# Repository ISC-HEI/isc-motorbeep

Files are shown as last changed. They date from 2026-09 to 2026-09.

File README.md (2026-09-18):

<picture>
  <source media="(prefers-color-scheme: dark)"
          srcset="https://raw.githubusercontent.com/ISC-HEI/isc-logos/main/white/ISC%20Logo%20inline%20white%20v3%20-%20large.webp">
  ISC Logo
</picture>

# ISC MotorBeep — ESP32 dual-stepper + audio board

A complete [KiCad 9](https://www.kicad.org/) schematic for an ESP32 board driving two bipolar
stepper motors and a small speaker, powered from 3× AA cells. It is an improved derivative of the
ESP32 DevKit DOIT v1: the AMS1117 LDO, the thin bulk capacitance, the micro-USB connector and the
absent battery sensing are all addressed.

## The brief

Take the [ESP32 DevKit DOIT v1](https://embedded-systems-design.github.io/overview-of-the-esp32-devkit-doit-v1/)
as the reference design and produce an improved version of it that drives **two stepper motors** and
a **small speaker**, running off **AA cells** — originally two, changed to three during the work.
Deliver the complete schematic in KiCad (installing it as needed), authored through the
[KiCAD-MCP-Server](https://github.com/mixelpixx/KiCAD-MCP-Server).

## What was built

1. KiCad 9 installed, the MCP server built, and patched — it emits the KiCad 10 file format, which 9 refuses to load.
2. Architecture chosen from the battery up: 3× AA (2.8–4.8 V) sits inside the STSPIN220 and MAX98357A supply windows, so motors and audio need no converter; only the ESP32 does, and it must be a buck-boost.
3. Parts picked against what KiCad actually ships — `DRV8834` and `TPS63020` have no stock symbols, so `STSPIN220` and `TPS63001` replaced them.
4. Four hierarchical sheets authored headlessly: power, MCU, motors, audio. **Root ERC: 0 errors.**
5. Verified three ways — ERC, a rendered image of every sheet reviewed by eye, and `check_nets.py`, which asserts 29 design-intent connections against the exported netlist.
6. Footprints assigned and checked to exist, netlist and PDF exported, BOM priced against the real JLCPCB catalog (**$14.49**, part links in [`doc/BOM.md`](./doc/BOM.md)).
7. A 4-layer PCB created and fully placed — antenna overhanging the edge, switching nodes 4.3 mm — then rendered in 3D. **Routing was not done.**

## Schematic

Four hierarchical sheets plus a root. Click any image for full resolution, or read
[the complete PDF](./doc/isc-motorbeep-schematic.pdf).

### Root — sheet hierarchy

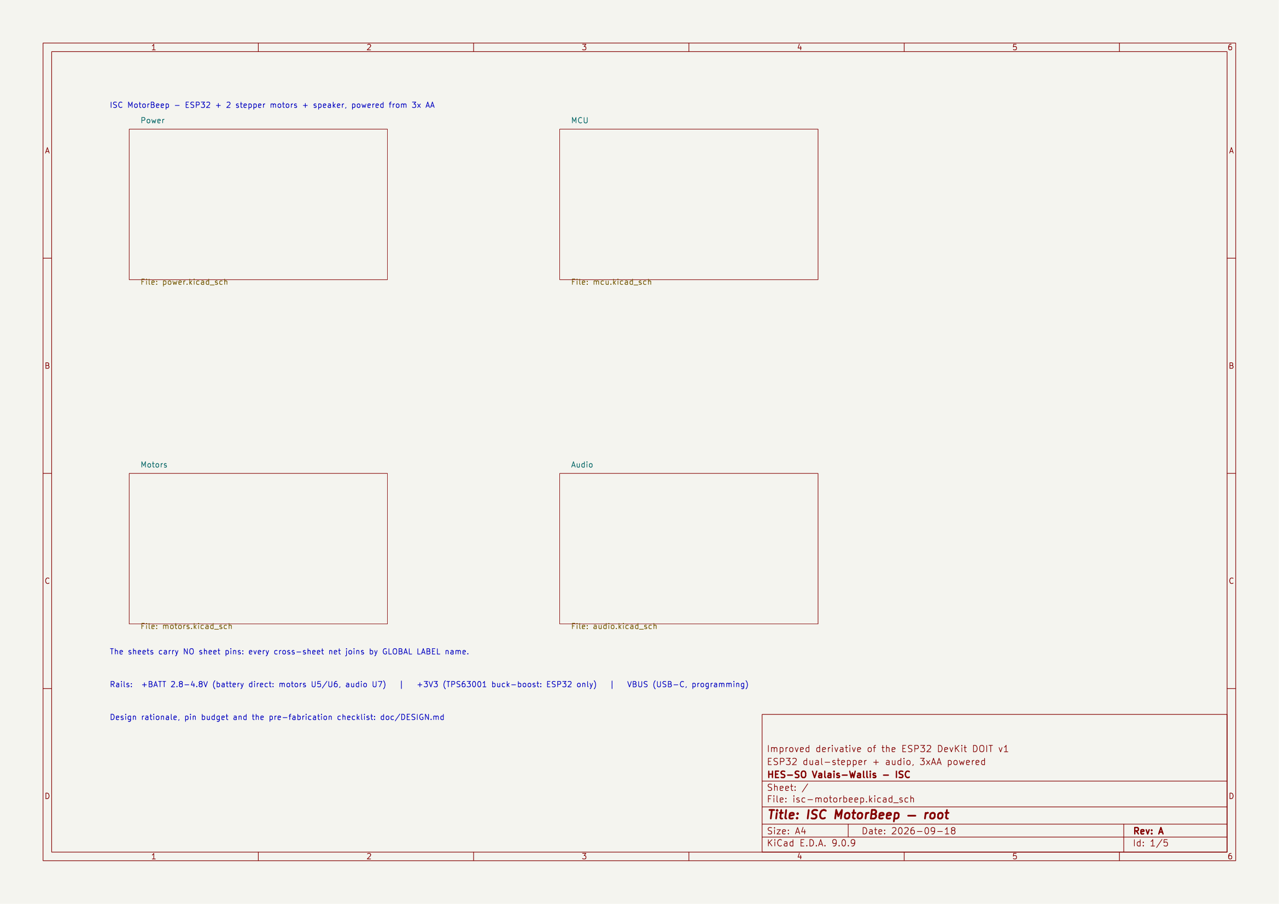
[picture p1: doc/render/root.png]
Root sheet


### Power — 3× AA, Schottky OR, TPS63001 buck-boost, USB-C

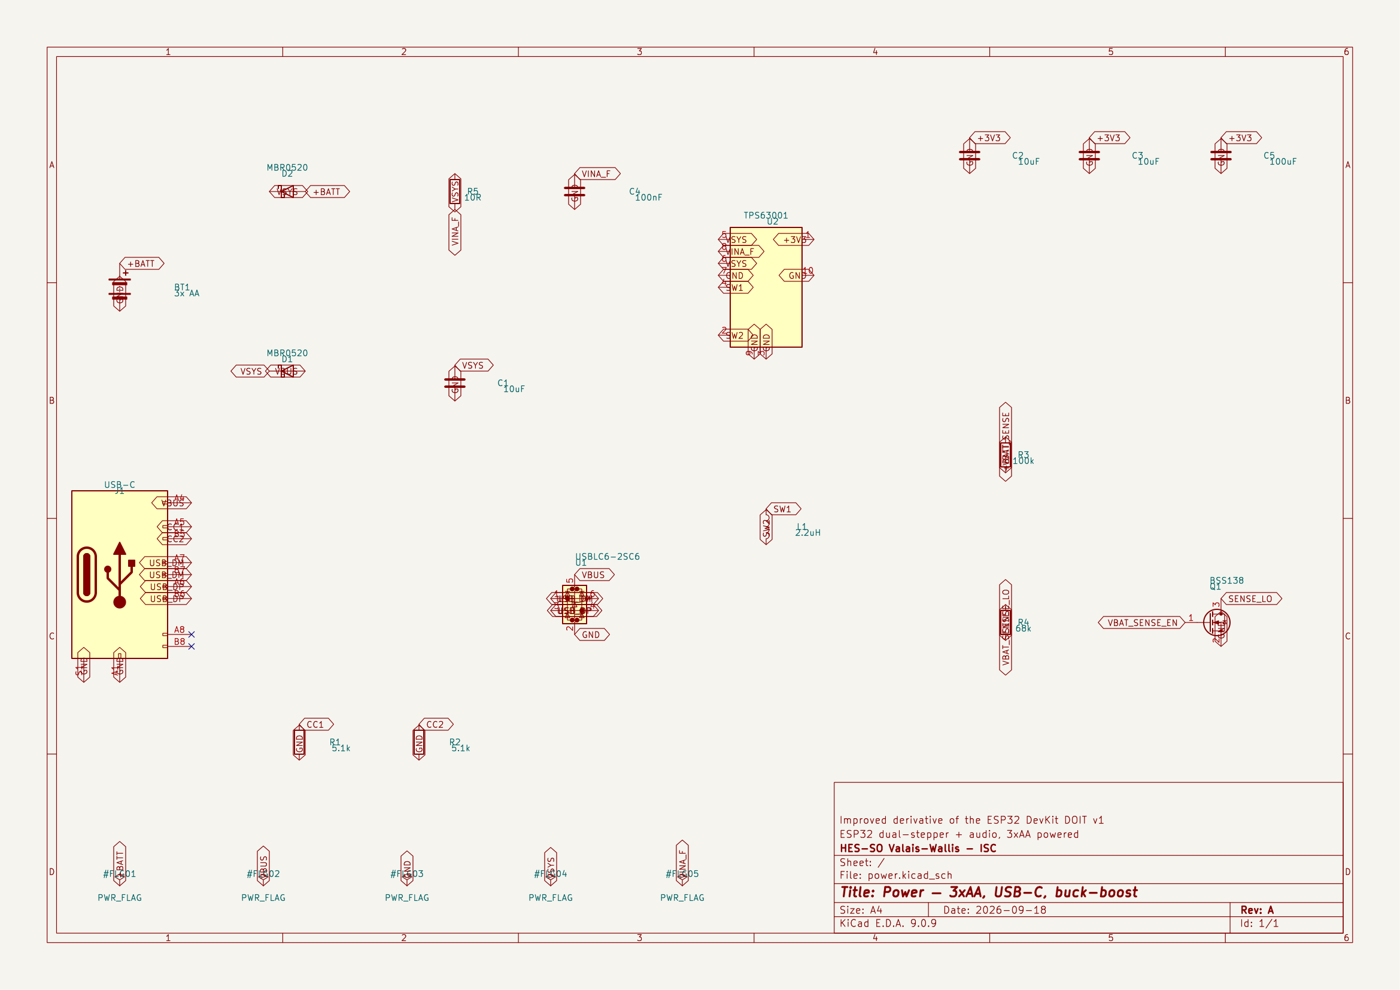
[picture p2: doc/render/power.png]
Power sheet


### MCU — ESP32-WROOM-32E, CP2102N bridge, auto-reset

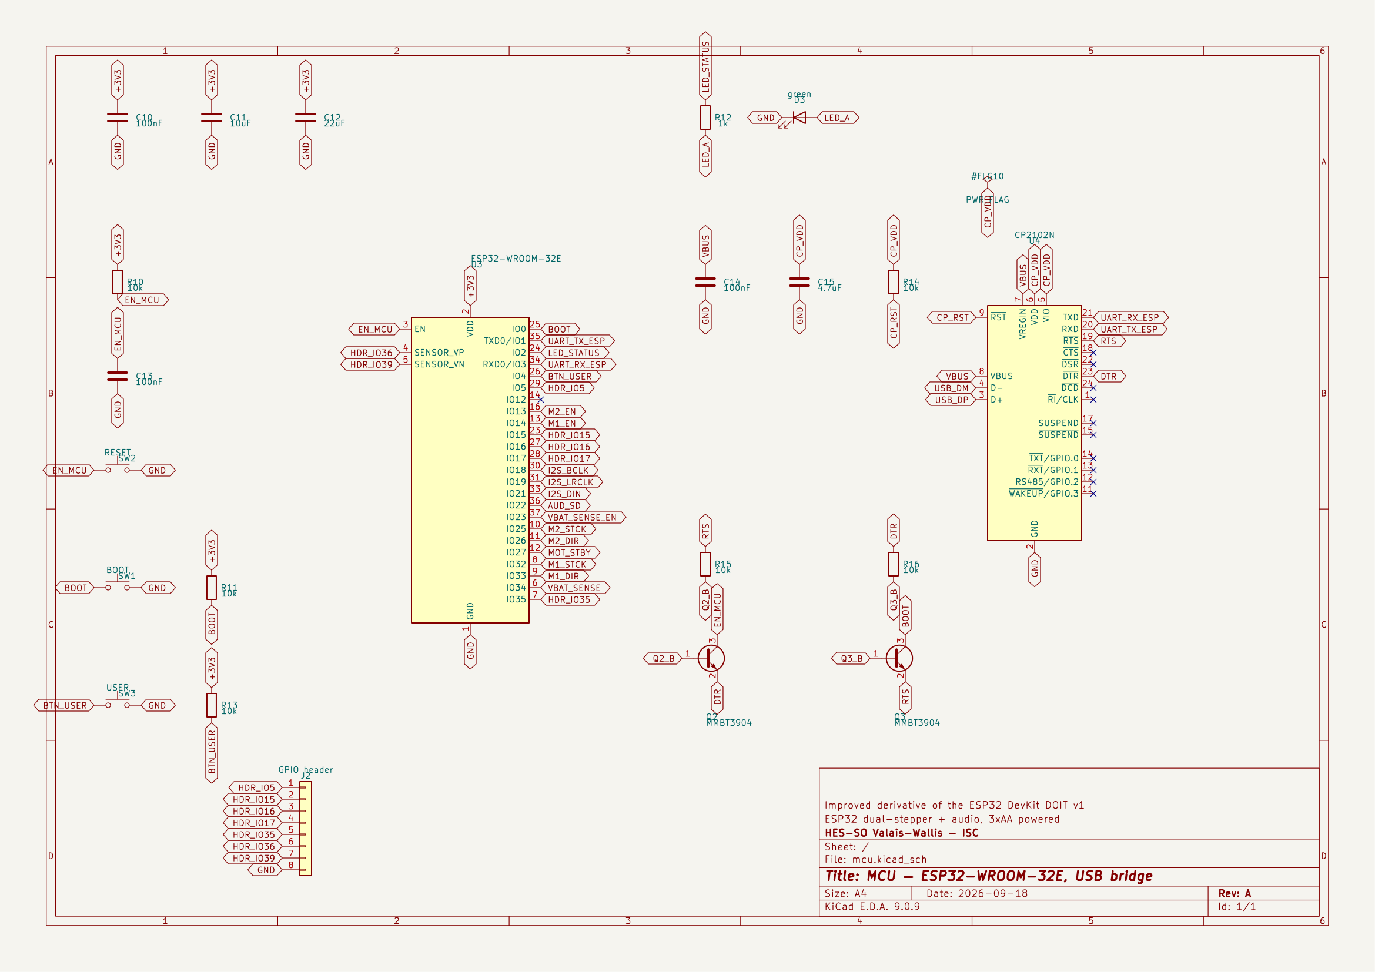
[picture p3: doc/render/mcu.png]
MCU sheet


### Motors — 2× STSPIN220 stepper drivers

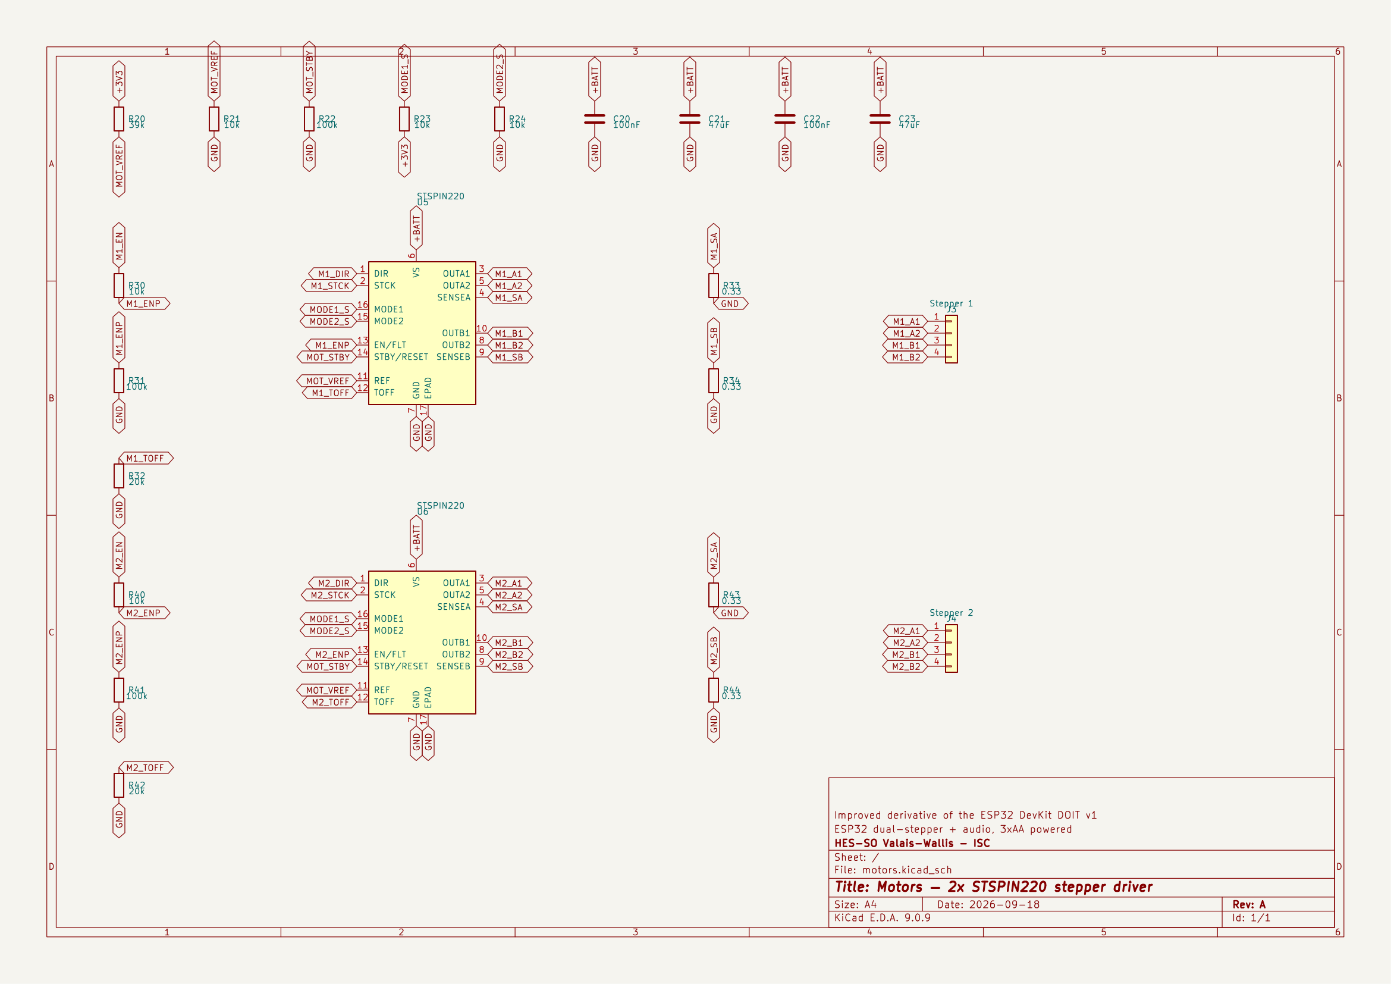
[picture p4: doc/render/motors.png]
Motors sheet


### Audio — MAX98357A Class-D

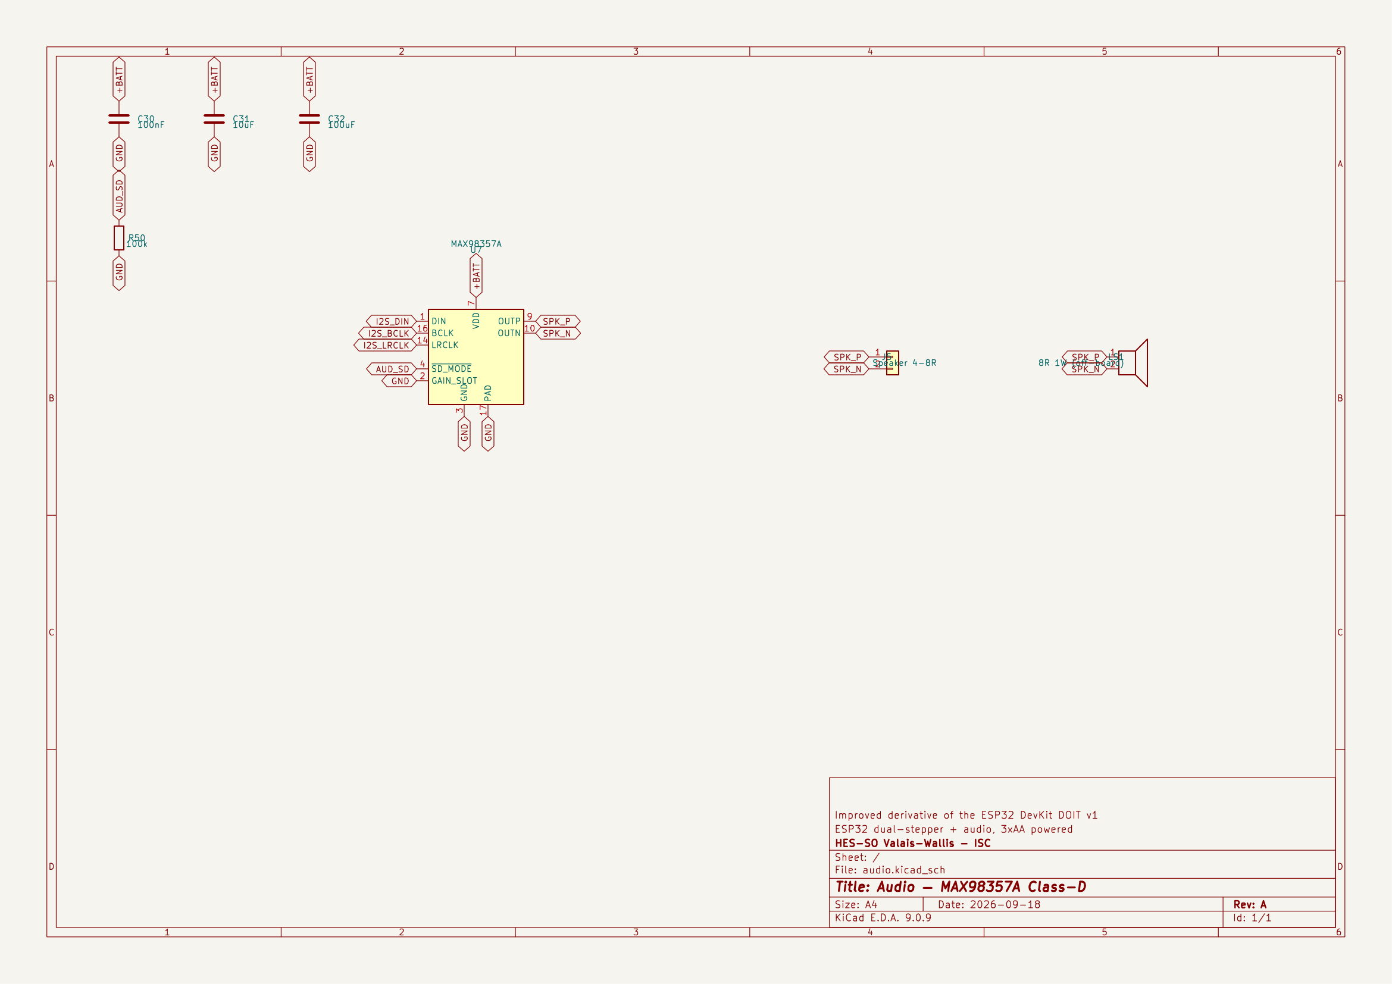
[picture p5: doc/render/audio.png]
Audio sheet


## PCB

Placed, not routed. 70 x 50 mm, 4 layers, 69 footprints, verified by
[`tools/place_board.py`](./tools/place_board.py): no overlaps, nothing off-board, and nothing
inside the ESP32 antenna keepout. The module's antenna deliberately overhangs the top edge, and
L1 sits directly left of the TPS63001 so both switching nodes come out as 4.3 mm straight runs.

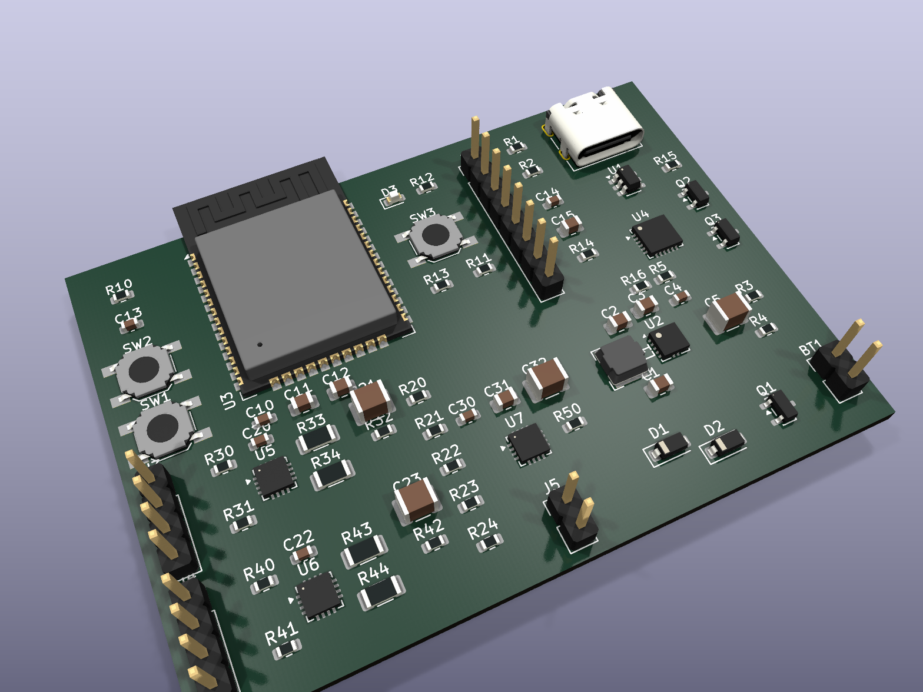
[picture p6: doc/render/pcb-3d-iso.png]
PCB 3D view


Routing is not done, so there are no tracks and no copper pours yet.

## Architecture

Three AA cells deliver 2.8–4.8 V, and that range sits inside the supply window of both power loads —
the STSPIN220 works from 1.8 V and the MAX98357A from 2.5 V — so the motors and the speaker run
straight off the pack with no converter at all. Only the ESP32 needs one, and it has to be a
buck-boost: the pack starts above 3.3 V and ends below it, so an LDO would drop out and a plain
boost could not regulate down. USB and battery are OR'd through two Schottky diodes into that
converter only, which is what stops USB from back-feeding and charging the alkaline cells.

```mermaid
flowchart LR
    B["3x AA / 2.8-4.8 V"] --> D2["D2 Schottky"]
    U["USB-C 5 V"] --> D1["D1 Schottky"]
    D1 --> V["VSYS"]
    D2 --> V
    V --> R["U2 TPS63001 buck-boost"]
    R --> L3["+3V3 - ESP32 only"]
    B --> M["U5/U6 STSPIN220 - 2 steppers"]
    B --> A["U7 MAX98357A - speaker"]
```

Every line the ESP32 gates has a resistor defining its state at reset, so the motors cannot twitch
and the speaker cannot pop at power-up; `GPIO12` is left unconnected because it straps the flash
voltage. The reasoning, the full pin budget and the pre-fabrication checklist are in
**[`doc/DESIGN.md`](./doc/DESIGN.md)**.

## Bill of materials

70 components in 36 lines, about **$14.49** in parts at 1-off LCSC prices (catalog snapshot of
14 September 2026). Full priced BOM with a part link per line: **[`doc/BOM.md`](./doc/BOM.md)**.

> [!WARNING]
> **The STSPIN220 was down to 27 units at JLCPCB in that snapshot** — check it live before
> committing to a build. `doc/BOM.md` names the substitute and what swapping costs you.

Almost every part is a JLCPCB *Extended* part with a $3 setup fee each, so for a one-off, hand
assembly is cheaper than paying the setup fees.

## Open it

```bash
kicad hardware/isc-motorbeep/isc-motorbeep.kicad_pro
```

Generated headlessly through the KiCAD-MCP-Server — reproduction steps, the KiCad 9 file-format
patch it needs, and the helper scripts are in [`doc/TOOLING.md`](./doc/TOOLING.md).

## Before fabricating

The schematic is complete and ERC-clean, but two questions could not be settled without
manufacturer datasheets. Both are detailed, with the rest of the checklist, in
[`doc/DESIGN.md` §8.5–8.6](./doc/DESIGN.md):

- **Are the STSPIN220 and MAX98357A logic inputs rated independently of their supply?** The ESP32
  drives 3.3 V into them while `+BATT` may be at 2.8 V. If either is VS-referenced, the design
  breaks at low battery. This is the one that matters.
- **The QFN-16 exposed-pad dimension** for U5/U6/U7 — stock footprint variants run 1.45 to 1.85 mm,
  and it is the thermal path the current-chopping depends on.

---

## License

Copyright © 2026 P.-A. Mudry / ISC — HES-SO Valais. Released under
[CC-BY-NC-ND 4.0](https://creativecommons.org/licenses/by-nc-nd/4.0/).

---

*Made with ♥ by mui, 2026*

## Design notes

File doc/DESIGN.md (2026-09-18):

# ISC MotorBeep — ESP32 dual-stepper + audio board, 3xAA powered

Improved derivative of the ESP32 DevKit DOIT v1.
Target: 2 stepper motors + 1 small speaker, powered from 3x AA cells.

## 1. The supply: 3x AA

| Chemistry | Fresh | Nominal | Practical cutoff | Usable energy |
|---|---|---|---|---|
| Alkaline 3xAA  | 4.8 V | 4.5 V | ~2.8 V | ~11 Wh at low current |
| NiMH 3xAA | 4.2 V | 3.6 V | 3.0 V | ~7 Wh, good pulse behaviour |

Going from 2 to 3 cells changes the architecture, it does not just add margin:

- **The motor and audio rails no longer need a converter.** The pack stays
  inside the STSPIN220 (1.8-10 V) and MAX98357A (2.5-5.5 V) supply ranges for
  the whole discharge, so both run **straight off VBAT**. The 5 V boost that
  2xAA forced is deleted: fewer parts, less EMI, and no conversion loss on the
  dominant load.
- **The 3.3 V logic rail still needs a buck-boost.** The pack starts at 4.8 V
  (above 3.3) and ends at 2.8 V (below it), so it crosses the output voltage.
  An LDO would drop out; a plain boost cannot regulate down. This stays
  non-negotiable.
- ~50% more energy than 2xAA, and the boost is gone, so runtime improves by
  appreciably more than 50%.

**Still recommended: NiMH (Eneloop) over alkaline.** Alkaline internal
resistance rises steeply as it discharges, and stepper coil current is pulsed;
the pack voltage will sag under each step. NiMH holds up far better.

## 2. Power architecture

    3xAA --> VBAT (2.8-4.8 V)
      |
      +--> U5, U6  STSPIN220   VS   direct   (1.8-10 V range)   motors
      +--> U7      MAX98357A   VDD  direct   (2.5-5.5 V range)  audio
      +--> U2      TPS63001 buck-boost -----> +3V3              ESP32 + logic

One converter in the whole design. `TPS63001` is the fixed-3.3 V member of the
TPS63000 family (Vin 1.8-5.5 V, 1.7 A switch); on the fixed-output parts **FB is
tied to GND**. Powering the ESP32 through a buck-boost also means it rides
through the VBAT sag caused by motor current pulses instead of browning out.

There is **no load switch** on the motor/audio domain: the STSPIN220 `STBY` and
the MAX98357A `SD_MODE` already put those parts in sub-microamp standby, so a
series FET would add loss and parts for nothing.

### 2.1 USB power path — and the back-feed trap it avoids

USB is for programming, but the board must also be usable with the pack in
place, so the two sources have to be OR'd **without letting USB charge the
batteries**. Alkaline cells being charged is a leak-and-rupture hazard.

The obvious circuit is wrong: a P-MOSFET reverse-polarity "ideal diode" with its
gate at GND is only a diode *until it turns on* — after that it conducts in both
directions. With VBUS = 5 V sitting above VBAT = 4.8 V it would push current
straight back into the pack. So:

    VBUS ---|>|--- D1 Schottky ---+
                                  +--- VIN of U2 (TPS63001) only
    VBAT ---|>|--- D2 Schottky ---+

    VBAT ------------------------------> motors + audio  (battery only, never USB)

- Diodes, not a FET, on the OR: they cannot conduct backwards, so USB can never
  reach the cells.
- The OR feeds **only the 3.3 V converter**. Motors and audio stay on the
  battery, which also stops a 500 mA USB port being asked to drive two steppers.
- Schottky drop ~0.3 V: at a flat pack, 2.8 - 0.3 = 2.5 V, still above the
  TPS63001 1.8 V minimum.
- The reverse-polarity FET is therefore only needed in the battery leg; with
  the Schottky there it becomes optional (see 8.5).

## 3. Stepper drivers — STSPIN220

**STSPIN220 x2** (U5, U6), QFN16 + exposed pad. Chosen because its supply range
starts at **1.8 V**: the usual A4988 / DRV8825 need 8 V and simply cannot run
from a battery pack this size. STEP/DIR ("STCK"/"DIR") interface, microstepping
to 1/256, integrated current control.

Motors are small **bipolar** steppers. Bipolar with current chopping is far more
efficient per unit of torque than the classic 28BYJ-48 unipolar + ULN2003, which
burns power in a Darlington array and has no current regulation at all.

Per-driver pins that need deliberate treatment:

| Pin | # | Treatment |
|---|---|---|
| `STCK`, `DIR` | 2, 1 | from ESP32 |
| `MODE1`, `MODE2` | 16, 15 | resistor straps -> microstep mode |
| `STBY/RESET` | 14 | **pull-down**; ESP32 raises to leave standby |
| `EN/FLT` | 13 | bidirectional: 10k series from GPIO + pull-down, so the open-drain fault can pull it low without fighting the GPIO |
| `REF` | 11 | divider from +3V3 sets the current limit |
| `TOFF` | 12 | resistor to GND sets the chopper off-time |
| `SENSEA`, `SENSEB` | 4, 9 | sense resistors to GND |
| `EPAD` | 17 | to GND — it is the thermal path |

**Microstep latching:** on the STSPIN220 the mode is latched when the device
leaves standby, and `MODE3`/`MODE4` are *multiplexed onto the `STCK`/`DIR`
pins*. Firmware must therefore set STCK/DIR to the wanted mode bits **before**
raising `STBY`, not after. This is the single easiest thing to get wrong.

## 4. Audio

**MAX98357A** (U7): I2S digital input -> Class-D output, 2.5-5.5 V supply,
~92% efficient, no separate DAC needed. Replaces the ESP32's own 8-bit DAC +
analog amp: better SNR, and Class-D matters when the energy budget is 5 Wh.
Runs directly from **VBAT**, `SD_MODE` gated by the ESP32 to mute/shutdown.

## 5. What is actually improved vs. the DOIT DevKit v1

| DOIT v1 weakness | Fix here |
|---|---|
| AMS1117 LDO: ~1.1 V dropout, no low-power mode, burns Vin-Vout as heat | TPS63001 buck-boost; motors/audio need no converter at all |
| Thin bulk capacitance near module -> brownout on WiFi TX bursts | 22 uF bulk + 10 uF + 100 nF at the module, plus a 100 uF reservoir on +3V3 |
| Micro-USB | USB-C receptacle, CC1/CC2 5.1k pulldowns |
| CP2102 (old), no ESD protection on USB | CP2102N + USBLC6-2SC6 ESD array |
| No reverse-polarity protection | Schottky D2 in the battery leg (also the OR-ing diode) |
| No battery sensing | divider on an **ADC1** pin, gated by a MOSFET so it draws nothing when idle |
| ADC2 pins unusable while WiFi is on (silent trap) | all analog routed to ADC1 only |
| Strapping pins exposed with no guidance | GPIO0/2/15 kept free of boot-breaking loads; **GPIO12 left NC** (anything on it risks a bad flash-voltage strap) |
| EN/BOOT buttons with marginal RC | proper RC + the two-transistor DTR/RTS auto-reset |

## 6. Sheet plan (hierarchical)

1. `power.kicad_sch`  — battery, Schottky OR, TPS63001 buck-boost, USB-C + ESD, battery sensing
2. `mcu.kicad_sch`    — ESP32-WROOM-32E, decoupling, CP2102N, auto-reset, buttons, LED
3. `motors.kicad_sch` — 2x STSPIN220 + shared bias/straps + connectors
4. `audio.kicad_sch`  — MAX98357A + speaker connector

## 7. Pin budget (ESP32-WROOM-32E)

| Function | GPIO | Note |
|---|---|---|
| M1 `STCK` / `DIR` | 32 / 33 | also carry MODE3/MODE4 at standby exit |
| M2 `STCK` / `DIR` | 25 / 26 | idem |
| Motors `STBY` (shared) | 27 | pull-down: both drivers asleep at reset |
| M1 `EN/FLT` | 14 | 10k series, bidirectional fault line |
| M2 `EN/FLT` | 13 | separate, so a fault is attributable to one motor |
| I2S `BCLK` / `LRCLK` / `DIN` | 18 / 19 / 21 | MAX98357A |
| Audio `SD_MODE` | 22 | mute / channel select |
| VBAT sense | 34 | **ADC1**_CH6, input-only pin |
| VBAT sense gate | 23 | MOSFET, divider draws nothing when idle |
| Status LED | 2 | strapping pin; LED to GND is the safe use |
| User button | 4 | |
| BOOT button | 0 | with the DTR/RTS auto-reset |
| — | **12** | **left NC** — MTDI straps the flash voltage |

Free and brought to a header: GPIO5, 15, 35, 36, 39.

## 8. Detail decisions (review pass)

Things that are easy to get wrong and are fixed deliberately here.

### 8.1 Default-safe straps — the important one
At ESP32 reset every GPIO is high-Z. Anything the ESP32 gates must therefore
have a resistor defining the safe state, or the motors twitch and the speaker
pops at power-up:

| Net | Pull | Why |
|---|---|---|
| `MOT_STBY` (GPIO27 -> both STSPIN220 `STBY`) | 100k **pull-down** | drivers stay in standby, coils unpowered |
| `M1_EN`, `M2_EN` (GPIO14/13 -> `EN/FLT`) | 100k **pull-down** + 10k series | outputs disabled; series R lets the open-drain fault win without fighting the GPIO |
| `AUD_SD` (GPIO22 -> `SD_MODE`) | see 8.3 | amp muted until driven |

**Caveat on GPIO14 (`M1_EN`).** GPIO14 is MTMS and has an *internal pull-up*
active during boot. Through the 10k series resistor against the 100k pull-down
it settles around 2 V, i.e. a logic HIGH, so `M1_EN` is briefly asserted while
the ESP32 boots. This is harmless **only because `STBY` (GPIO27) is the master
gate and has no boot pull** — the driver stays in standby regardless, so no
current reaches the coils. If that ordering ever changes, move the EN lines to
GPIO16/17, which have no boot pulls.

### 8.2 STSPIN220 — current limit and the two easy mistakes
Phase current is set by the `REF` voltage together with the `SENSEA`/`SENSEB`
resistors; `TOFF` sets the chopper off-time. Planned: Rsense = 0.33 ohm, a
39k/10k divider from +3V3 giving VREF ~= 0.67 V, TOFF resistor for ~20 us.
**The exact VREF-to-current gain is a datasheet check before fab** (see 8.5) —
the divider is placed so the ratio can be retrimmed without a layout change.

Two mistakes this design avoids:
- `EPAD` (pin 17) is the only thermal path — tied to GND, not left floating.
- Microstep mode is latched leaving standby and `MODE3`/`MODE4` sit on the
  `STCK`/`DIR` pins, so firmware sets those **before** raising `STBY`.

### 8.3 MAX98357A — SD_MODE is dual-purpose
`SD_MODE` is not a plain shutdown pin: the resistor from it to GND **selects the
channel** through the voltage it develops with the internal pull-up — (L+R)/2,
L only, or R only. The value is therefore chosen deliberately (100k -> (L+R)/2
mono sum, what a single small speaker wants), and the ESP32 pulls the pin low to
mute. `GAIN_SLOT` to GND selects 15 dB, right for a small 4-8 ohm speaker.

Output power tracks VBAT (P ~ V^2), so the speaker gets quieter as the pack
drains. For a "petit haut-parleur" there is ample headroom either way.

### 8.4 CP2102N powered from VBUS, not +3V3
The USB bridge runs off `VREGIN` = VBUS through its own internal LDO, so it
draws **nothing from the battery** when USB is unplugged. (This is the one thing
the DOIT board already gets right; it is kept.)

### 8.5 Open items to confirm against datasheets before fab
Stated as checks, not as facts:
- **STSPIN220 `REF` -> phase-current gain**, and the `TOFF` resistor value for
  the chosen off-time. The divider and Rsense above are a starting point.
- **TPS63001 output current at Vin = 2.8 V.** The ESP32-WROOM-32E datasheet
  (Table 14, Recommended Operating Conditions) requires the external supply to
  deliver **0.5 A minimum** — this is a specified requirement, not an estimate.
  Confirm the buck-boost still delivers 0.5 A at 3.3 V from a nearly-flat pack;
  its 1.7 A switch rating suggests yes, but the low-Vin curve is the check.
- **Reverse-polarity protection is the Schottky, not a FET.** The 2xAA draft
  carried a P-MOSFET ideal diode; the built design does not, because D2 already
  blocks reverse current and a FET behind it would add nothing but Rds(on). The
  cost is D2's ~0.3 V drop, already accounted for above. No DMG2301L in the BOM.
- **Logic-level abs-max on both loads.** The ESP32 drives 3.3 V logic into the
  STSPIN220 and MAX98357A while their own supply may be as low as 2.8 V. Both
  are believed to rate their digital inputs independently of VS (to ~5 V), but
  **if either input rating is VS-referenced the design is broken at low
  battery**. One datasheet line each settles it; it is the single most
  consequential open item on this list.
- **ERC housekeeping:** `PWR_FLAG` on `VBAT` and `VBUS`, otherwise ERC reports
  "power pin not driven" on every rail. *(Done — root ERC is at 0 errors.)*

### 8.6 Footprint notes

- **USB-C J1 symbol and footprint do match.** An earlier revision of this
  document claimed they did not. That was wrong: it came from a pin extractor
  that silently truncated long symbol definitions and reported 11 of the 17
  pins. `USB_C_Receptacle_USB2.0_16P` and
  `USB_C_Receptacle_G-Switch_GT-USB-7010ASV` agree exactly - 17 pins, 17 pads,
  no pad without a net (verified against the exported netlist, not the symbol
  file). The same truncation bug also under-reported the ESP32 module as 29
  pins instead of 39; that one was harmless because the missing pins were
  duplicate GNDs and the module's own NC pins.
- **QFN-16 exposed-pad size is provisional.** U5/U6 (STSPIN220) and U7
  (MAX98357A) are assigned
  `QFN-16-1EP_3x3mm_P0.5mm_EP1.45x1.45mm_ThermalVias`. The body and pitch are
  right; **confirm the exposed-pad dimension** against each datasheet — stock
  variants range from 1.45 to 1.85 mm and the wrong one degrades the thermal
  path that 8.2 depends on.

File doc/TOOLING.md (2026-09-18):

# How this schematic was generated

The schematic was authored without opening the KiCad GUI, by driving the
[KiCAD-MCP-Server](https://github.com/mixelpixx/KiCAD-MCP-Server) over stdio. This file records
what is needed to reproduce that, and the traps worth knowing. None of it is required to *use*
the schematic — for that, open the project in KiCad 9.

## Prerequisites

| Tool | Why | Debian/Ubuntu | macOS |
|---|---|---|---|
| KiCad 9 | `pcbnew`, `kicad-cli`, symbol + footprint libraries | `sudo add-apt-repository ppa:kicad/kicad-9.0-releases && sudo apt install kicad` | `brew install --cask kicad` |
| Node.js ≥ 18 | the MCP server itself | `sudo apt install nodejs npm` | `brew install node` |
| Python ≥ 3.11 | `kicad-skip`, `sexpdata`, `pymupdf` | `sudo apt install python3 python3-venv` | `brew install python` |

The server is cloned into `tools/kicad-mcp-server/` and is **not** tracked here — it is a
third-party project with its own history. `.mcp.json` registers it for Claude Code and contains
absolute paths; adjust them to wherever you cloned it.

Two setup snags on Ubuntu 24.04: `python3 -m venv` produces a venv with no `pip` (bootstrap it with
`get-pip.py`), and the venv cannot see KiCad's `pcbnew` unless you drop a `.pth` file naming
`/usr/lib/python3/dist-packages` into its `site-packages`.

## The KiCad 10 vs 9 file format problem

The server writes `(version 20260101)`, the KiCad 10 schematic format. KiCad 9 refuses those files
with no better diagnostic than `Failed to load schematic`. The fix is three lines and is described
in [`KICAD9-PATCH.md`](./KICAD9-PATCH.md). Re-apply it after pulling the server upstream.

## Scripts in `tools/`

| Script | Does |
|---|---|
| `pins.py` | prints a library symbol's pins, resolving `(extends …)`, so nets are wired against real pin numbers |
| `place.py` | emits component-move batches with every origin snapped to the 2.54 mm connection grid |
| `check_nets.py` | parses the exported netlist and asserts each design-intent net reaches the pins it should |
| `price_bom.py` | prices the BOM against the server's offline JLCPCB catalog and writes [`BOM.md`](./BOM.md) |
| `render.sh` | exports a sheet to SVG + PNG and prints its ERC |

`kmcp.mjs`, the minimal stdio MCP client used to call the server (`list` / `schema` / `call` /
`batch`), lives inside the untracked server directory because it resolves the server's own
`node_modules`.

## Traps

- **Off-grid origins break ERC.** Placing parts on round millimetre coordinates puts their pins off
  the 2.54 mm connection grid, and KiCad then reports *"Symbol pin or wire end off connection grid"*
  for every one. `place.py` snaps origins so this cannot happen.
- **Per-sheet ERC is not the real ERC.** Cross-sheet global labels look dangling on their own sheet.
  Only `run_erc` on the root schematic is meaningful.
- **"Connected N pins" is not verification.** The server reports success for labels it placed, not
  for a netlist KiCad agrees with. `check_nets.py` closes that gap, and it is what caught the pin
  mapping questions recorded in `DESIGN.md` §8.6.
- **Parse symbol files by paren depth, not by lookahead.** A bounded regex over a `(pin …)` block
  silently drops pins with long name/effects blocks — it reported the ESP32 module as 29 pins
  instead of 39, and the USB-C receptacle as 11 instead of 17. That produced one wrong conclusion
  that survived into a published README before the netlist contradicted it.

## Adding a sheet

1. `create_hierarchical_subsheet` against `isc-motorbeep.kicad_sch` — creates the file and links it.
2. Add parts with `batch_add_and_connect` and `labelType: "global_label"`; cross-sheet nets join by name.
3. Snap origins with `place.py`, then `autoplace_schematic_fields` and `suggest_schematic_declutter`.
4. `run_erc` on the **root**.
5. Add the sheet's nets to `check_nets.py`, render it, and look at the PNG.

## 3D rendering without root

`kicad-cli pcb render` produces the views in `render/`. It needs the STEP models,
which ship in `kicad-packages3d` — a root install. If you cannot use `sudo`, the
models can go in your home directory instead, because KiCad resolves them through
a variable the footprints already reference:

```bash
mkdir -p ~/.local/share/kicad-3dmodels && cd ~/.local/share/kicad-3dmodels
curl -L -o pk3d.tar.gz \
  "https://gitlab.com/kicad/libraries/kicad-packages3D/-/archive/9.0.9/kicad-packages3D-9.0.9.tar.gz"
tar xzf pk3d.tar.gz            # 633 MB download, 3.2 GB extracted
export KICAD9_3DMODEL_DIR=~/.local/share/kicad-3dmodels/kicad-packages3D-9.0.9
```

Then render, passing the same variable through to the tool:

```bash
kicad-cli pcb render --output out.png --width 1600 --height 1200 \
  --quality high --perspective --floor --rotate "-30,0,25" --background opaque \
  --define-var KICAD9_3DMODEL_DIR=$KICAD9_3DMODEL_DIR \
  hardware/isc-motorbeep/isc-motorbeep.kicad_pcb
```

Note the GitLab archive contains **only `.step`** — the `.wrl` files are generated
at packaging time and are absent. That is fine here: KiCad 9 footprints reference
`.step` directly.

Four footprints have no model in the library at all (the G-Switch USB-C, the two
QFN sizes and the Texas VSON-10). `tools/fix_3d_models.py` repoints those at
equivalent bodies **for rendering only** — same package and pin count, different
exposed-pad size, which is hidden under the part. It touches nothing electrical.

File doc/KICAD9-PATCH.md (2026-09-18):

# Local patch: emit KiCad 9 schematic format

Upstream v2.7.0 creates schematics as `(version 20260101) (generator_version "10.0")`
(KiCad 10). KiCad 9.0.9 — the version this project targets, and the minimum the
server itself documents — refuses to load those files: `kicad-cli` reports only
`Failed to load schematic`.

Root cause is narrow. `dynamic_symbol_loader.py::_supports_kicad10_symbol_tokens`
already gates the KiCad-10-only tokens `(body_style N)` and `(in_pos_files yes)`
on the file's declared version, so it does the right thing *if the file declares
version 9*. Only the creation path was hardcoded to 10.

Changed the declared version to `20250114` / `"9.0"` in:

- `python/commands/schematic.py`   (create_schematic)
- `python/commands/project.py`     (project creation)
- `python/templates/blank.kicad_sch`

20250114 is readable by both KiCad 9 and 10 (10 upgrades on load), so this is
the safe target rather than a downgrade.

Re-apply after any `git pull` of the upstream server.

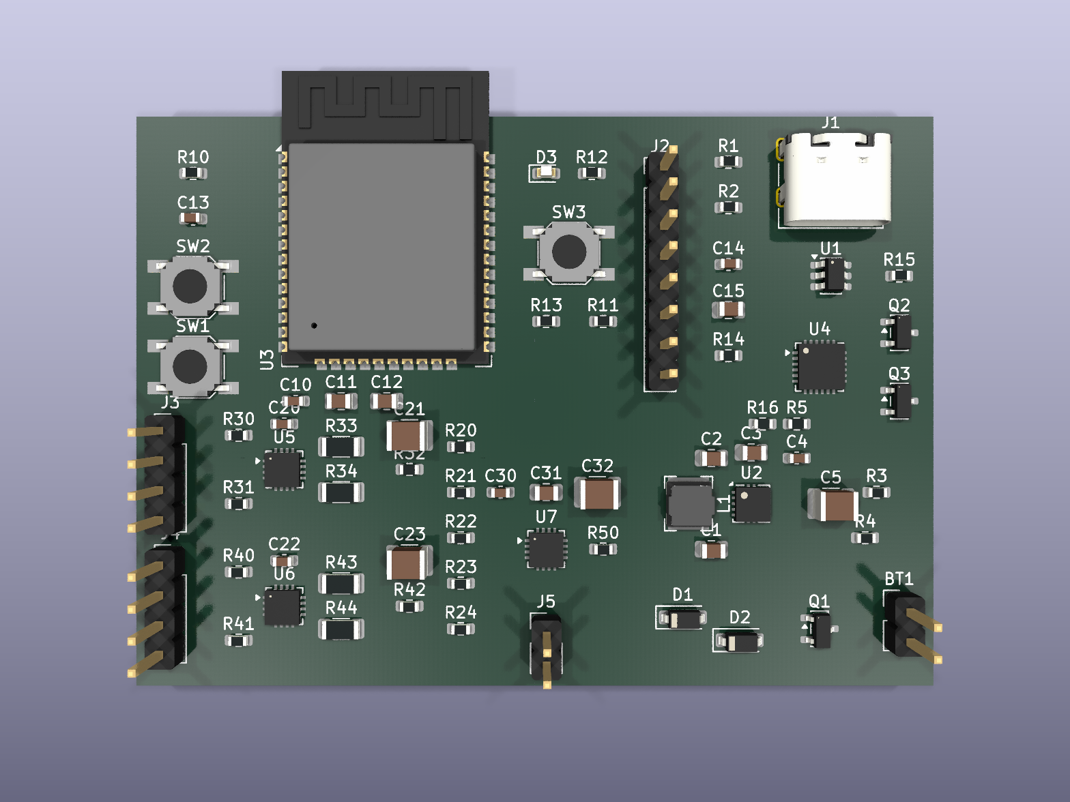
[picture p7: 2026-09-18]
doc/render/pcb-3d-top.png

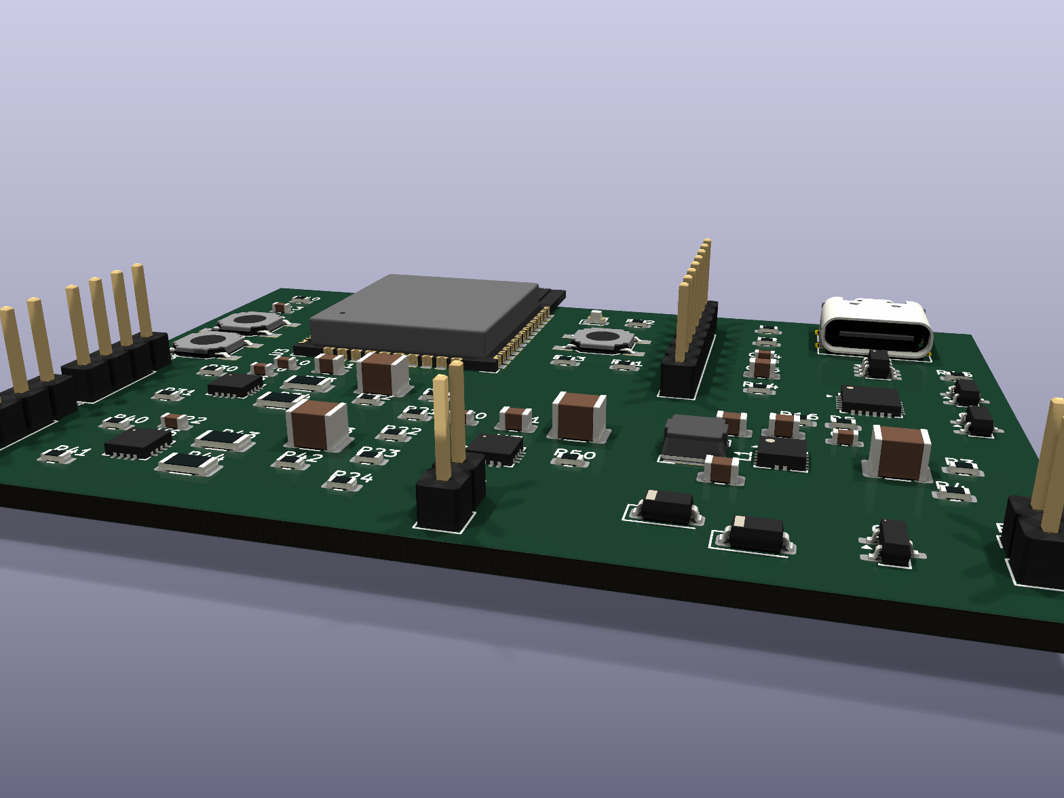
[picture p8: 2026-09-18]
doc/render/pcb-3d-low.png

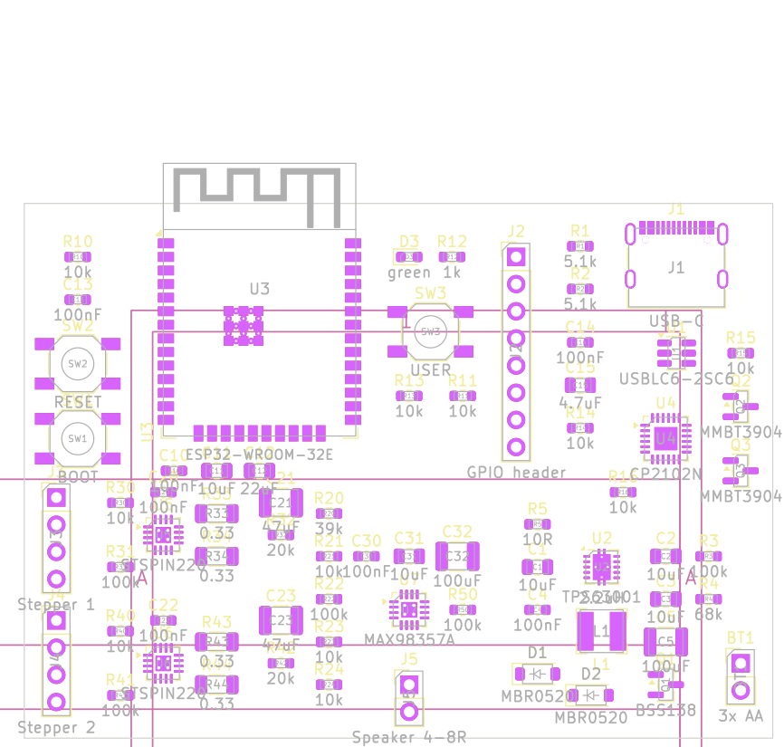
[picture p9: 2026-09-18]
doc/render/pcb-placement.png

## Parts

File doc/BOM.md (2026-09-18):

# Bill of materials — ISC MotorBeep

Generated by `tools/price_bom.py` from the KiCAD-MCP-Server's offline JLCPCB
catalog. Prices are 1-off LCSC breaks and **move constantly** — re-run after a
`download_jlcpcb_database` to refresh. Each row links to its part page.

| Ref | Value | Package | LCSC | Qty | Unit $ | Line $ | Stock |
|---|---|---|---|---:|---:|---:|---:|
| `BT1` | 3x AA | PinHeader_1x02_P2.54mm_Vertical | [C115246](https://jlcpcb.com/partdetail/115246) | 1 | 0.2166 | **0.22** | 2,949 |
| `C1-C3,C11,C31` | 10uF | C_0805_2012Metric | [C109040](https://jlcpcb.com/partdetail/109040) | 5 | 0.1089 | **0.54** | 6,534 |
| `C4,C10,C13,C14,C20,C22,C30` | 100nF | C_0603_1608Metric | [C113803](https://jlcpcb.com/partdetail/113803) | 7 | 0.0129 | **0.09** | 22,292 |
| `C5,C32` | 100uF | C_1210_3225Metric | [C16196526](https://jlcpcb.com/partdetail/16196526) | 2 | 0.7412 | **1.48** | 1,323 |
| `C12` | 22uF | C_0805_2012Metric | [C128856](https://jlcpcb.com/partdetail/128856) | 1 | 0.0928 | **0.09** | 20,058 |
| `C15` | 4.7uF | C_0805_2012Metric | [C106839](https://jlcpcb.com/partdetail/106839) | 1 | 0.0479 | **0.05** | 1,067 |
| `C21,C23` | 47uF | C_1210_3225Metric | [C16196538](https://jlcpcb.com/partdetail/16196538) | 2 | 0.2780 | **0.56** | 961 |
| `D1,D2` | MBR0520 | D_SOD-123 | [C22378360](https://jlcpcb.com/partdetail/22378360) | 2 | 0.0146 | **0.03** | 10,217 |
| `D3` | green | LED_0603_1608Metric | [C125102](https://jlcpcb.com/partdetail/125102) | 1 | 0.0166 | **0.02** | 109,618 |
| `J1` | USB-C | USB_C_Receptacle_G-Switch_GT-USB-7010ASV | [C165948](https://jlcpcb.com/partdetail/165948) | 1 | 0.1858 | **0.19** | 89,797 |
| `J2` | GPIO header | PinHeader_1x08_P2.54mm_Vertical | [C115246](https://jlcpcb.com/partdetail/115246) | 1 | — | *(same strip)* | 2,949 |
| `J3` | Stepper 1 | PinHeader_1x04_P2.54mm_Vertical | [C115246](https://jlcpcb.com/partdetail/115246) | 1 | — | *(same strip)* | 2,949 |
| `J4` | Stepper 2 | PinHeader_1x04_P2.54mm_Vertical | [C115246](https://jlcpcb.com/partdetail/115246) | 1 | — | *(same strip)* | 2,949 |
| `J5` | Speaker 4-8R | PinHeader_1x02_P2.54mm_Vertical | [C115246](https://jlcpcb.com/partdetail/115246) | 1 | — | *(same strip)* | 2,949 |
| `L1` | 2.2uH | L_Bourns-SRN4018 | [C107565](https://jlcpcb.com/partdetail/107565) | 1 | 0.0798 | **0.08** | 1,102 |
| `LS1` | 8R 1W (off-board) | — | — | 1 | — | — | — |
| `Q1` | BSS138 | SOT-23 | [C112239](https://jlcpcb.com/partdetail/112239) | 1 | 0.0176 | **0.02** | 271,091 |
| `Q2,Q3` | MMBT3904 | SOT-23 | [C22368849](https://jlcpcb.com/partdetail/22368849) | 2 | 0.0064 | **0.01** | 606 |
| `R1,R2` | 5.1k | R_0603_1608Metric | [C105580](https://jlcpcb.com/partdetail/105580) | 2 | 0.0020 | **0.00** | 5,622 |
| `R3,R22,R31,R41,R50` | 100k | R_0603_1608Metric | [C103200](https://jlcpcb.com/partdetail/103200) | 5 | 0.0014 | **0.01** | 517 |
| `R4` | 68k | R_0603_1608Metric | [C103818](https://jlcpcb.com/partdetail/103818) | 1 | 0.0010 | **0.00** | 725 |
| `R5` | 10R | R_0603_1608Metric | [C4297800](https://jlcpcb.com/partdetail/4297800) | 1 | 0.0026 | **0.00** | 5,241 |
| `R10,R11,R13-R16,R21,R23,R24,R30,R40` | 10k | R_0603_1608Metric | [C130232](https://jlcpcb.com/partdetail/130232) | 11 | 0.0038 | **0.04** | 1,192 |
| `R12` | 1k | R_0603_1608Metric | [C100835](https://jlcpcb.com/partdetail/100835) | 1 | 0.0012 | **0.00** | 2,564 |
| `R20` | 39k | R_0603_1608Metric | [C118370](https://jlcpcb.com/partdetail/118370) | 1 | 0.0006 | **0.00** | 4,415 |
| `R32,R42` | 20k | R_0603_1608Metric | [C101298](https://jlcpcb.com/partdetail/101298) | 2 | 0.0012 | **0.00** | 1,157 |
| `R33,R34,R43,R44` | 0.33 | R_1206_3216Metric | [C104942](https://jlcpcb.com/partdetail/104942) | 4 | 0.0079 | **0.03** | 4,803 |
| `SW1` | BOOT | SW_SPST_SKQG_WithoutStem | [C10852](https://jlcpcb.com/partdetail/10852) | 1 | 0.0225 | **0.02** | 892 |
| `SW2` | RESET | SW_SPST_SKQG_WithoutStem | [C10852](https://jlcpcb.com/partdetail/10852) | 1 | 0.0225 | **0.02** | 892 |
| `SW3` | USER | SW_SPST_SKQG_WithoutStem | [C10852](https://jlcpcb.com/partdetail/10852) | 1 | 0.0225 | **0.02** | 892 |
| `U1` | USBLC6-2SC6 | SOT-23-6 | [C47147619](https://jlcpcb.com/partdetail/47147619) | 1 | 0.0323 | **0.03** | 6,309 |
| `U2` | TPS63001 | Texas_DRC0010J_ThermalVias | [C28060](https://jlcpcb.com/partdetail/28060) | 1 | 1.7929 | **1.79** | 6,715 |
| `U3` | ESP32-WROOM-32E | ESP32-WROOM-32E | [C701341](https://jlcpcb.com/partdetail/701341) | 1 | 3.8183 | **3.82** | 20,082 |
| `U4` | CP2102N | QFN-24-1EP_4x4mm_P0.5mm_EP2.15x2.15mm | [C964632](https://jlcpcb.com/partdetail/964632) | 1 | 1.8059 | **1.81** | 14,927 |
| `U5,U6` | STSPIN220 | QFN-16-1EP_3x3mm_P0.5mm_EP1.45x1.45mm_ThermalVias | [C2150516](https://jlcpcb.com/partdetail/2150516) | 2 | 1.5033 | **3.01** | 27 |
| `U7` | MAX98357A | QFN-16-1EP_3x3mm_P0.5mm_EP1.45x1.45mm_ThermalVias | [C2682619](https://jlcpcb.com/partdetail/2682619) | 1 | 0.4995 | **0.50** | 16,467 |

**Total: $14.49 in parts for one board.**

## Notes

- `LS1` is the off-board speaker, deliberately unpriced — `J5` is the connector on the board.
- All five 2.54 mm headers are cut from one 1x40 strip (20 pins of 40), so the strip is counted once.
- Almost everything here is a JLCPCB *Extended* part, which carries a $3 setup fee each if you
  use their assembly service; for a one-off, hand assembly is cheaper than the setup fees.

## If the STSPIN220 is out of stock

It is the scarcest part in the design. The closest replacement is the **DRV8834**
(`C400392`, VQFN-24, or `C456273`, HTSSOP-24, ~$2.40). Its 2.5–10.8 V range still covers a
3x AA pack for its useful life, but it is not a drop-in: different footprint, and KiCad 9
ships no DRV8834 symbol, so the motors sheet would need a custom symbol and footprint.

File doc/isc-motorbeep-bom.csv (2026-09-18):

Reference | Value | Footprint | QUANTITY | DNP
BT1 | 3x AA | Connector_PinHeader_2.54mm:PinHeader_1x02_P2.54mm_Vertical | 1
C1-C3,C11,C31 | 10uF | Capacitor_SMD:C_0805_2012Metric | 5
C4,C10,C13,C14,C20,C22,C30 | 100nF | Capacitor_SMD:C_0603_1608Metric | 7
C5,C32 | 100uF | Capacitor_SMD:C_1210_3225Metric | 2
C12 | 22uF | Capacitor_SMD:C_0805_2012Metric | 1
C15 | 4.7uF | Capacitor_SMD:C_0805_2012Metric | 1
C21,C23 | 47uF | Capacitor_SMD:C_1210_3225Metric | 2
D1,D2 | MBR0520 | Diode_SMD:D_SOD-123 | 2
D3 | green | LED_SMD:LED_0603_1608Metric | 1
J1 | USB-C | Connector_USB:USB_C_Receptacle_G-Switch_GT-USB-7010ASV | 1
J2 | GPIO header | Connector_PinHeader_2.54mm:PinHeader_1x08_P2.54mm_Vertical | 1
J3 | Stepper 1 | Connector_PinHeader_2.54mm:PinHeader_1x04_P2.54mm_Vertical | 1
J4 | Stepper 2 | Connector_PinHeader_2.54mm:PinHeader_1x04_P2.54mm_Vertical | 1
J5 | Speaker 4-8R | Connector_PinHeader_2.54mm:PinHeader_1x02_P2.54mm_Vertical | 1
L1 | 2.2uH | Inductor_SMD:L_Bourns-SRN4018 | 1
LS1 | 8R 1W (off-board) |  | 1
Q1 | BSS138 | Package_TO_SOT_SMD:SOT-23 | 1
Q2,Q3 | MMBT3904 | Package_TO_SOT_SMD:SOT-23 | 2
R1,R2 | 5.1k | Resistor_SMD:R_0603_1608Metric | 2
R3,R22,R31,R41,R50 | 100k | Resistor_SMD:R_0603_1608Metric | 5
R4 | 68k | Resistor_SMD:R_0603_1608Metric | 1
R5 | 10R | Resistor_SMD:R_0603_1608Metric | 1
R10,R11,R13-R16,R21,R23,R24,R30,R40 | 10k | Resistor_SMD:R_0603_1608Metric | 11
R12 | 1k | Resistor_SMD:R_0603_1608Metric | 1
R20 | 39k | Resistor_SMD:R_0603_1608Metric | 1
R32,R42 | 20k | Resistor_SMD:R_0603_1608Metric | 2
R33,R34,R43,R44 | 0.33 | Resistor_SMD:R_1206_3216Metric | 4
SW1 | BOOT | Button_Switch_SMD:SW_SPST_SKQG_WithoutStem | 1
SW2 | RESET | Button_Switch_SMD:SW_SPST_SKQG_WithoutStem | 1
SW3 | USER | Button_Switch_SMD:SW_SPST_SKQG_WithoutStem | 1
U1 | USBLC6-2SC6 | Package_TO_SOT_SMD:SOT-23-6 | 1
U2 | TPS63001 | Package_SON:Texas_DRC0010J_ThermalVias | 1
U3 | ESP32-WROOM-32E | RF_Module:ESP32-WROOM-32E | 1
U4 | CP2102N | Package_DFN_QFN:QFN-24-1EP_4x4mm_P0.5mm_EP2.15x2.15mm | 1
U5,U6 | STSPIN220 | Package_DFN_QFN:QFN-16-1EP_3x3mm_P0.5mm_EP1.45x1.45mm_ThermalVias | 2
U7 | MAX98357A | Package_DFN_QFN:QFN-16-1EP_3x3mm_P0.5mm_EP1.45x1.45mm_ThermalVias | 1

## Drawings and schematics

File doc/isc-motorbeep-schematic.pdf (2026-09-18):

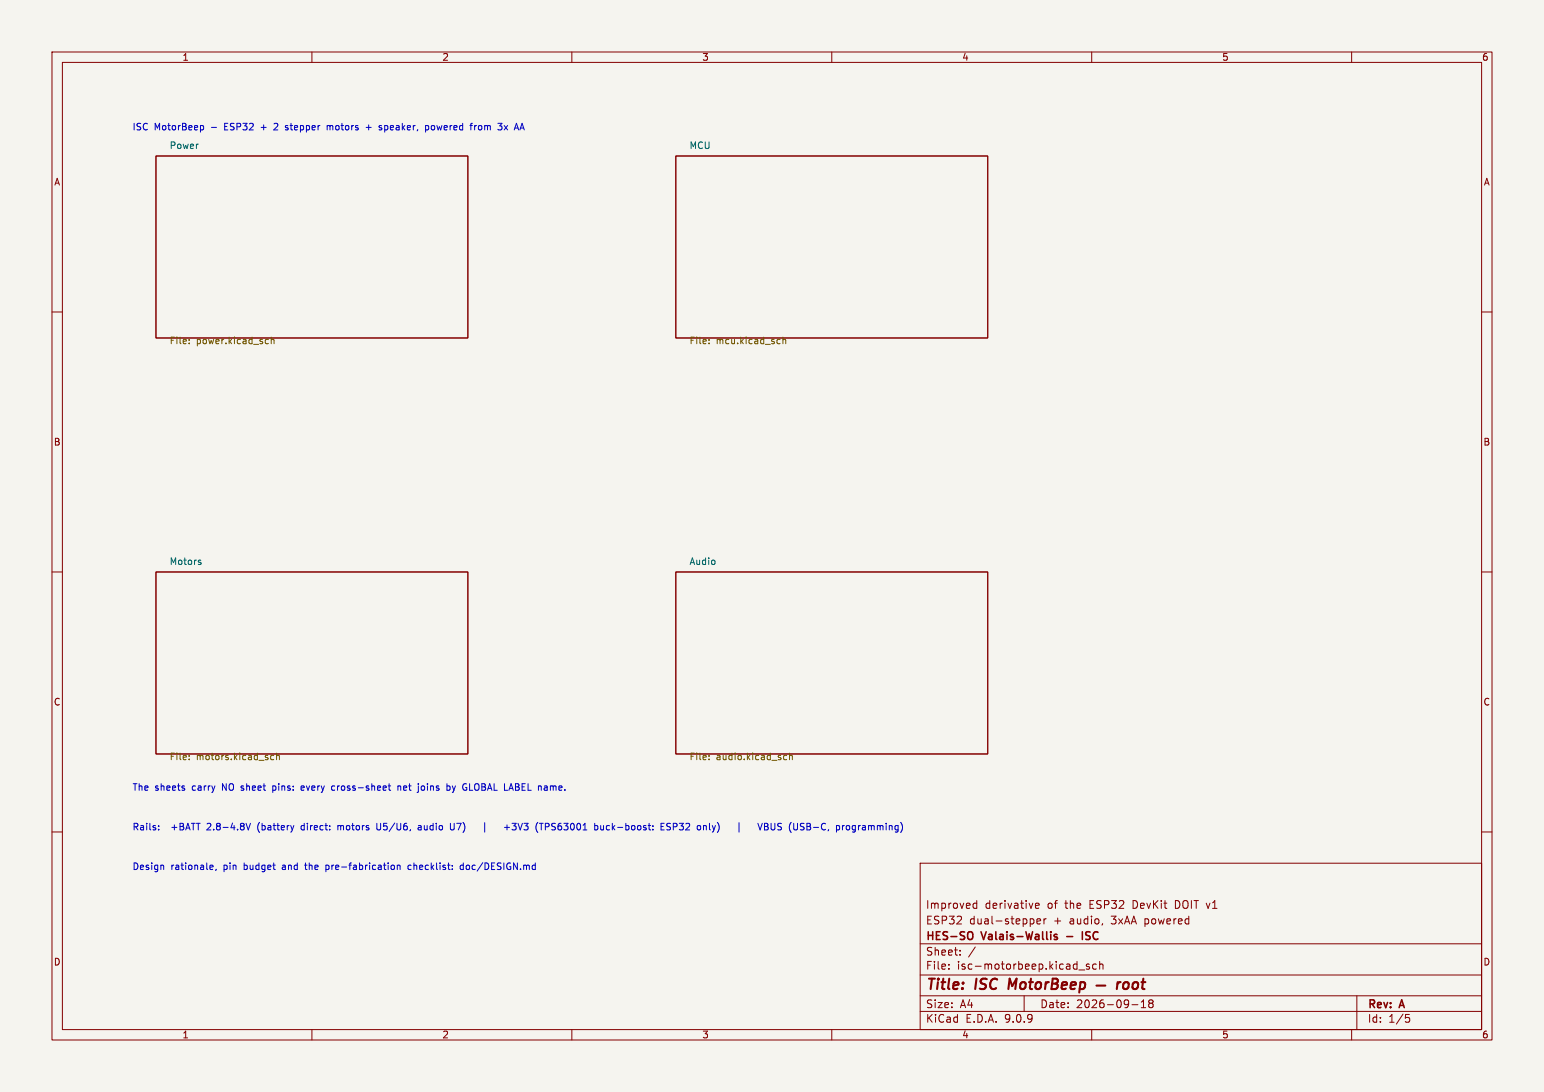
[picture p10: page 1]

ISC MotorBeep - ESP32 + 2 stepper motors + speaker, powered from 3x AA

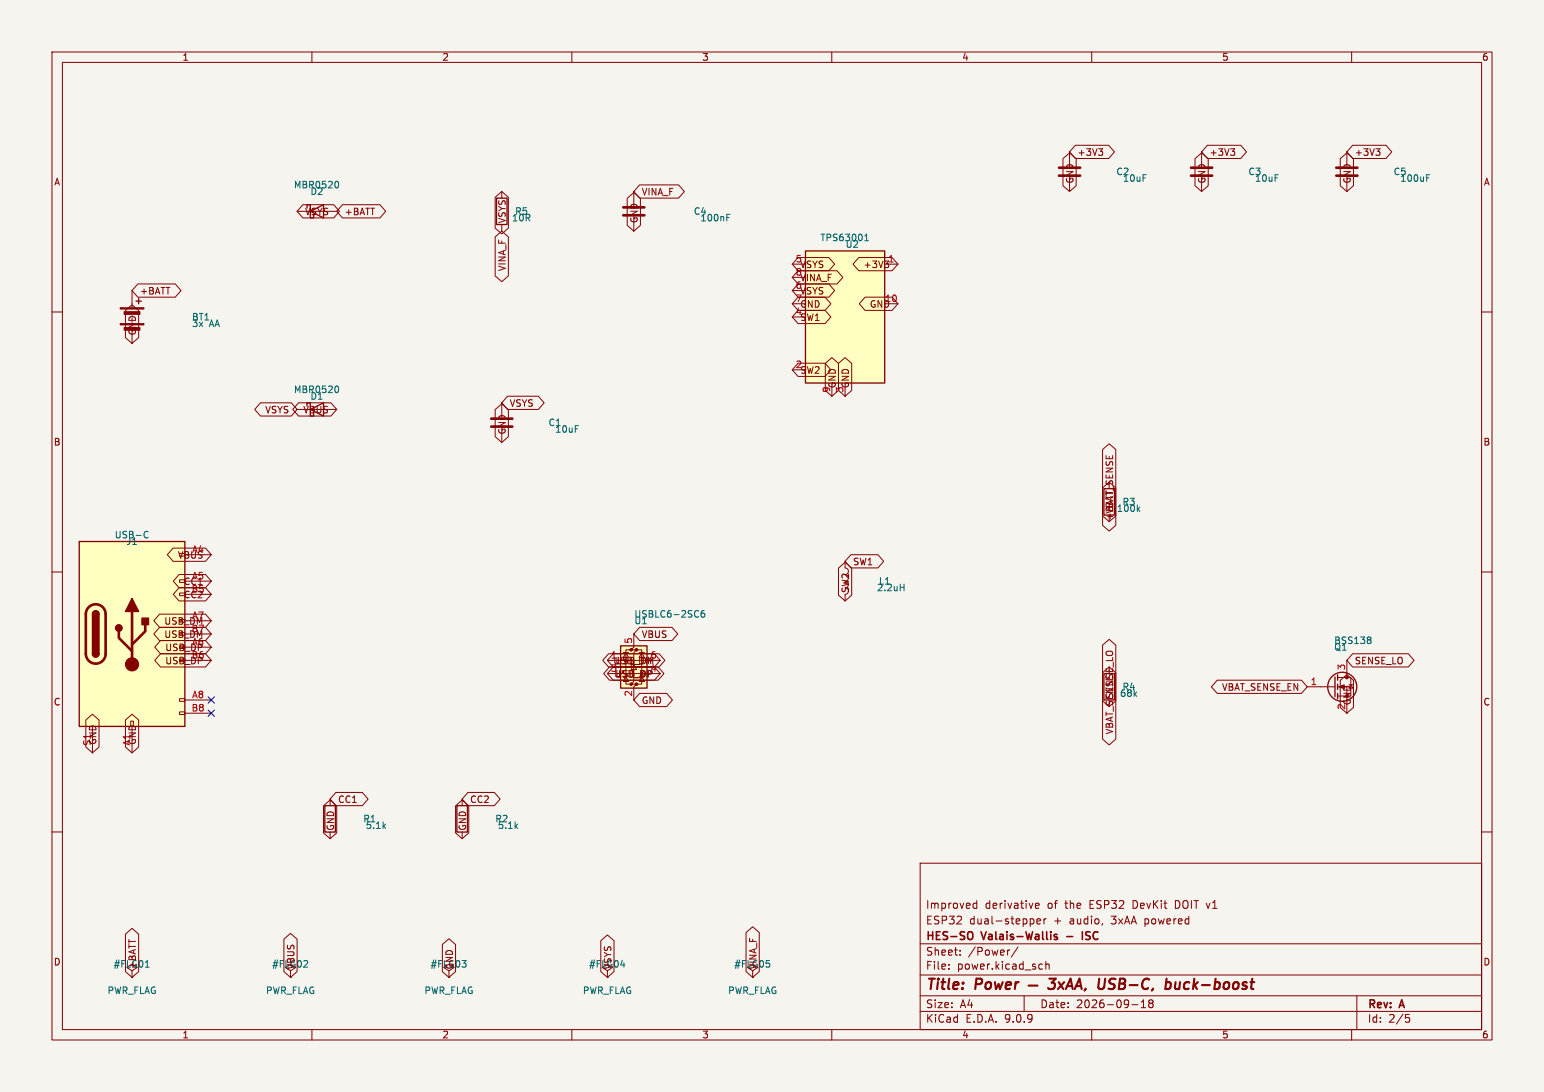
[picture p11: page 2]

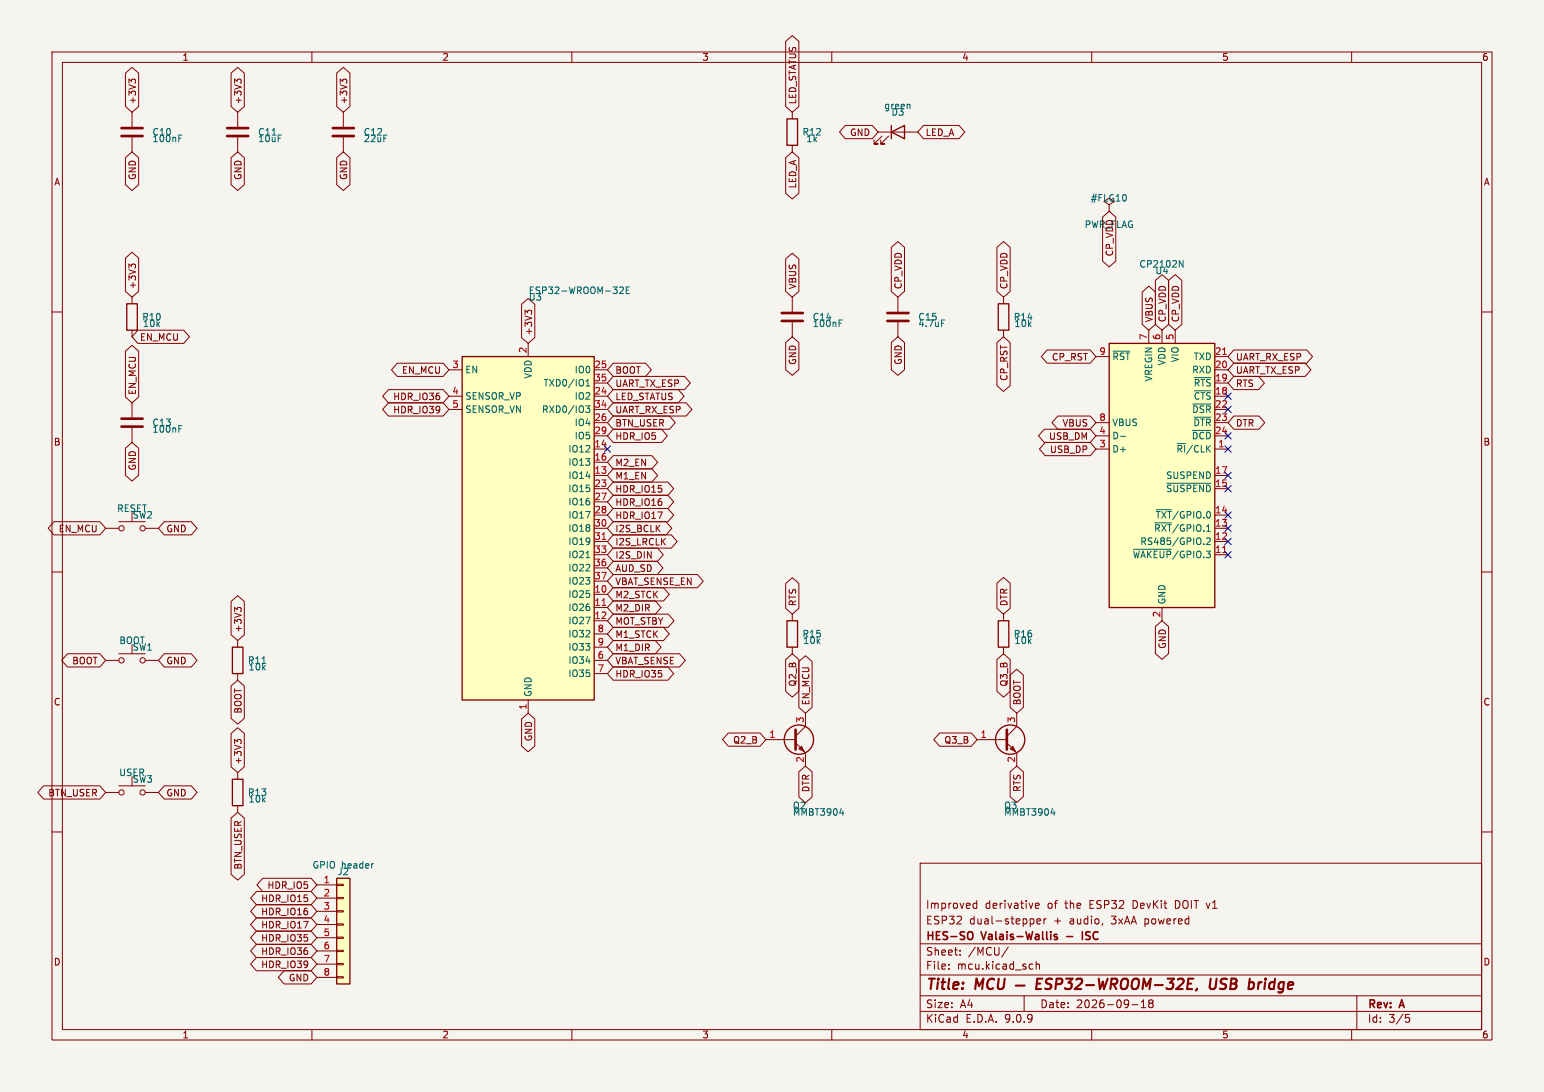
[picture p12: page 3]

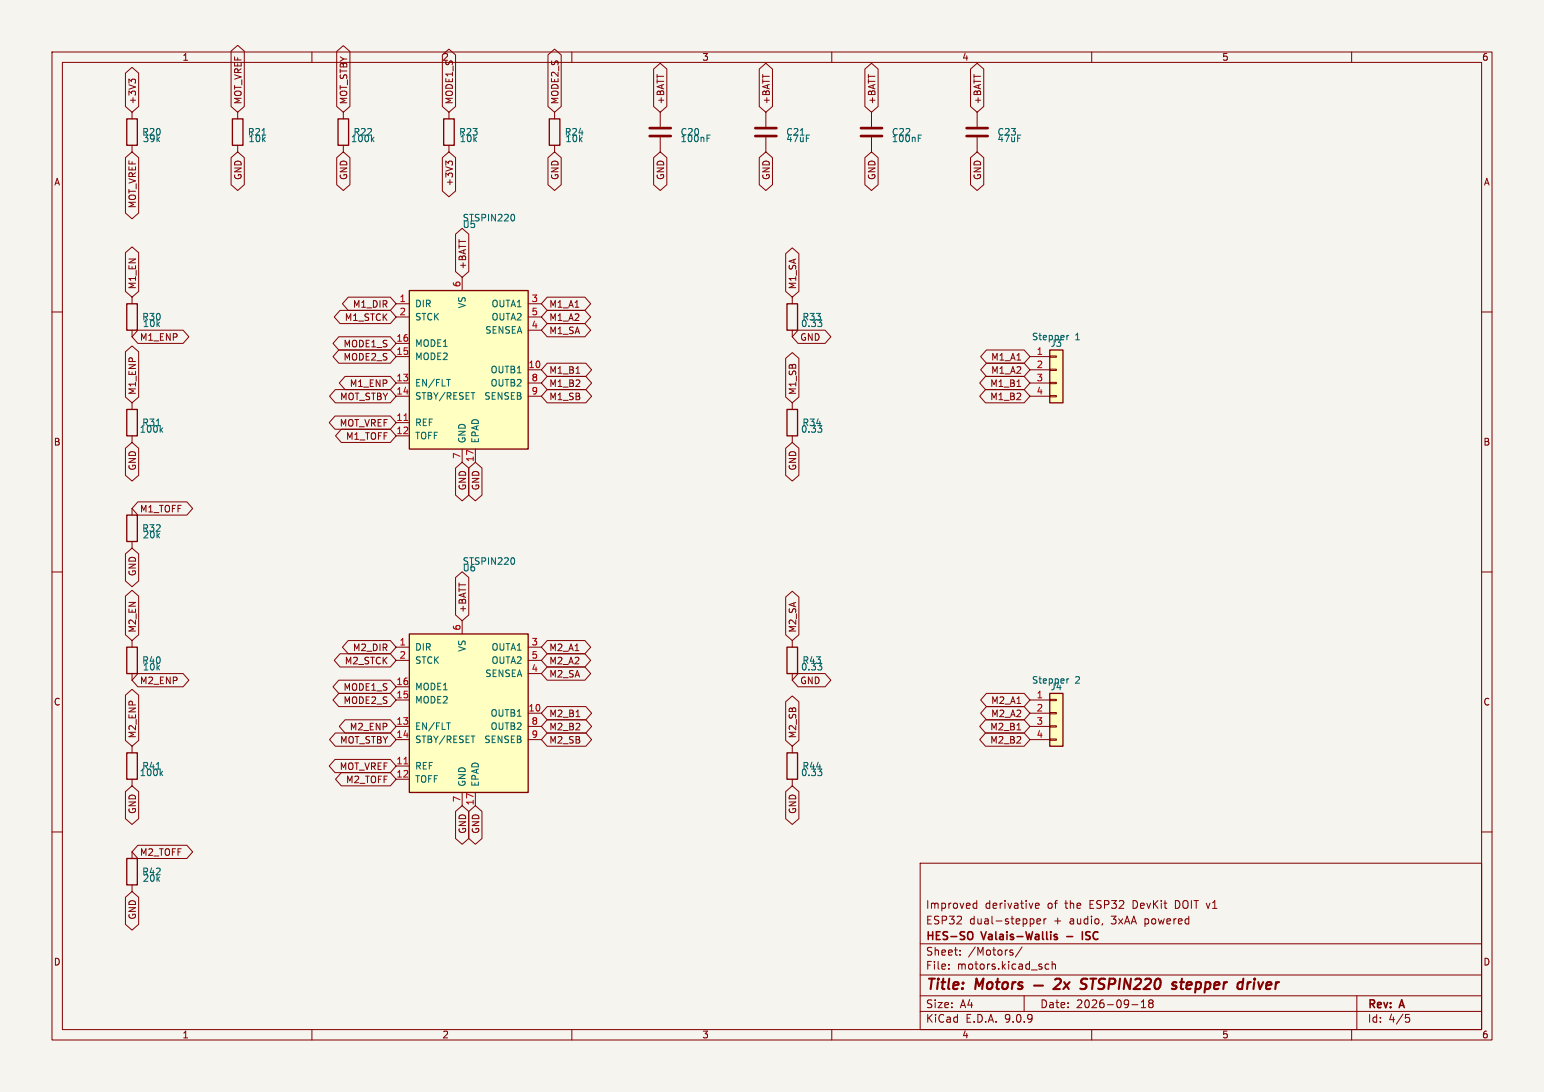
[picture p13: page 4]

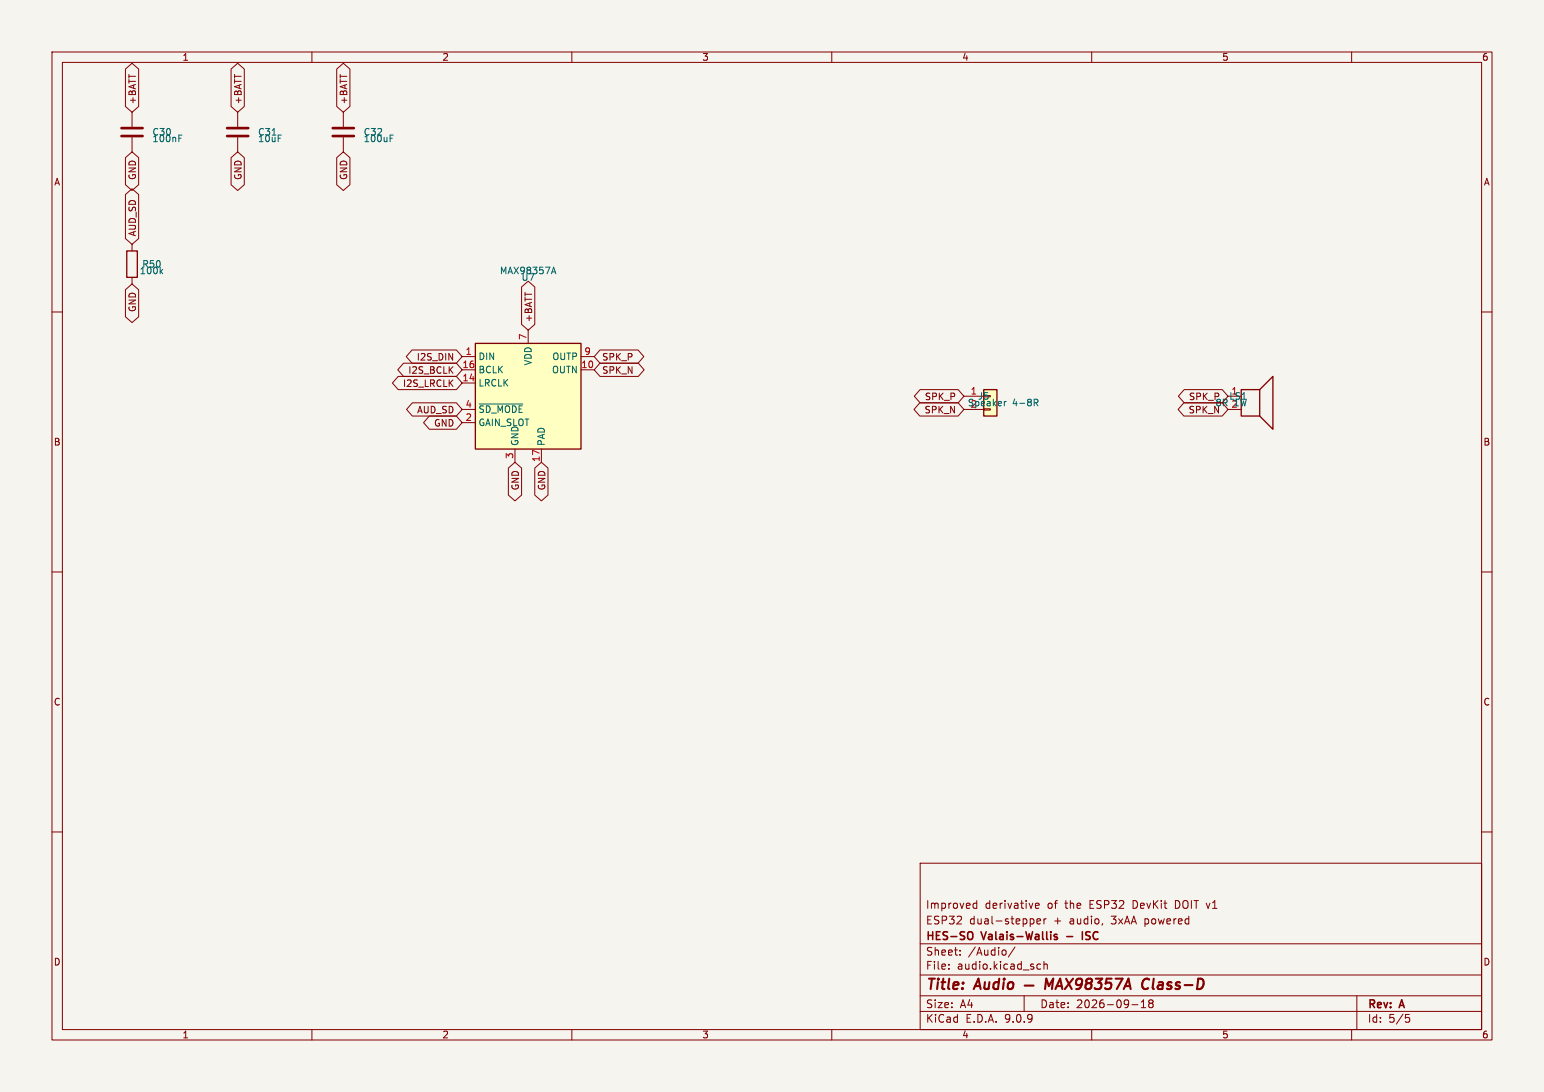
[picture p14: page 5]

Id: 5/5 Title: Audio þÿ MAX98357A Class-D

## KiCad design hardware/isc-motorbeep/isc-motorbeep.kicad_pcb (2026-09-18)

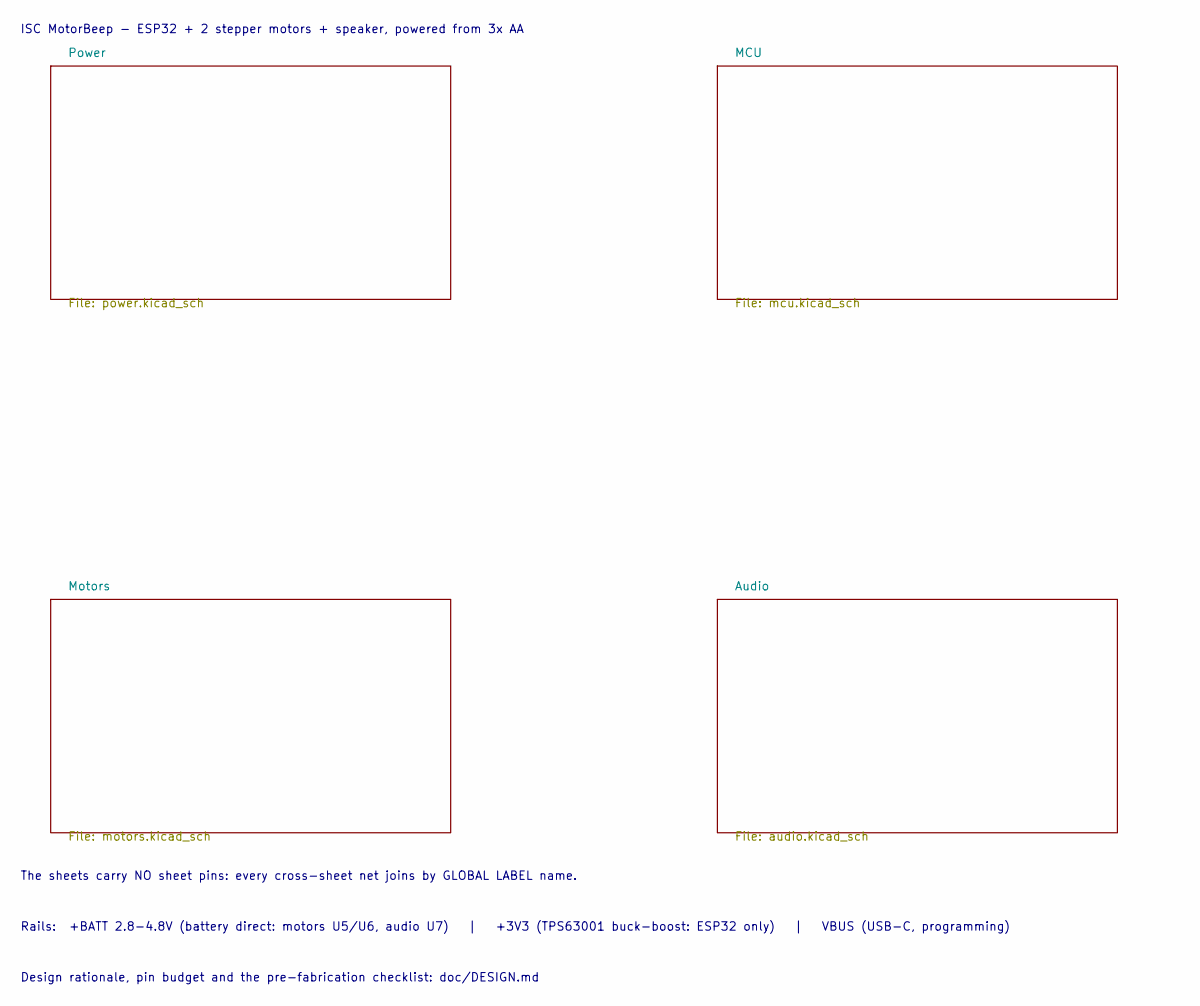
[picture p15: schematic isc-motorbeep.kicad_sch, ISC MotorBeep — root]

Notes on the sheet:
ISC MotorBeep - ESP32 + 2 stepper motors + speaker, powered from 3x AA
The sheets carry NO sheet pins: every cross-sheet net joins by GLOBAL LABEL name.
Rails: +BATT 2.8-4.8V (battery direct: motors U5/U6, audio U7) | +3V3 (TPS63001 buck-boost: ESP32 only) | VBUS (USB-C, programming)
Design rationale, pin budget and the pre-fabrication checklist: doc/DESIGN.md

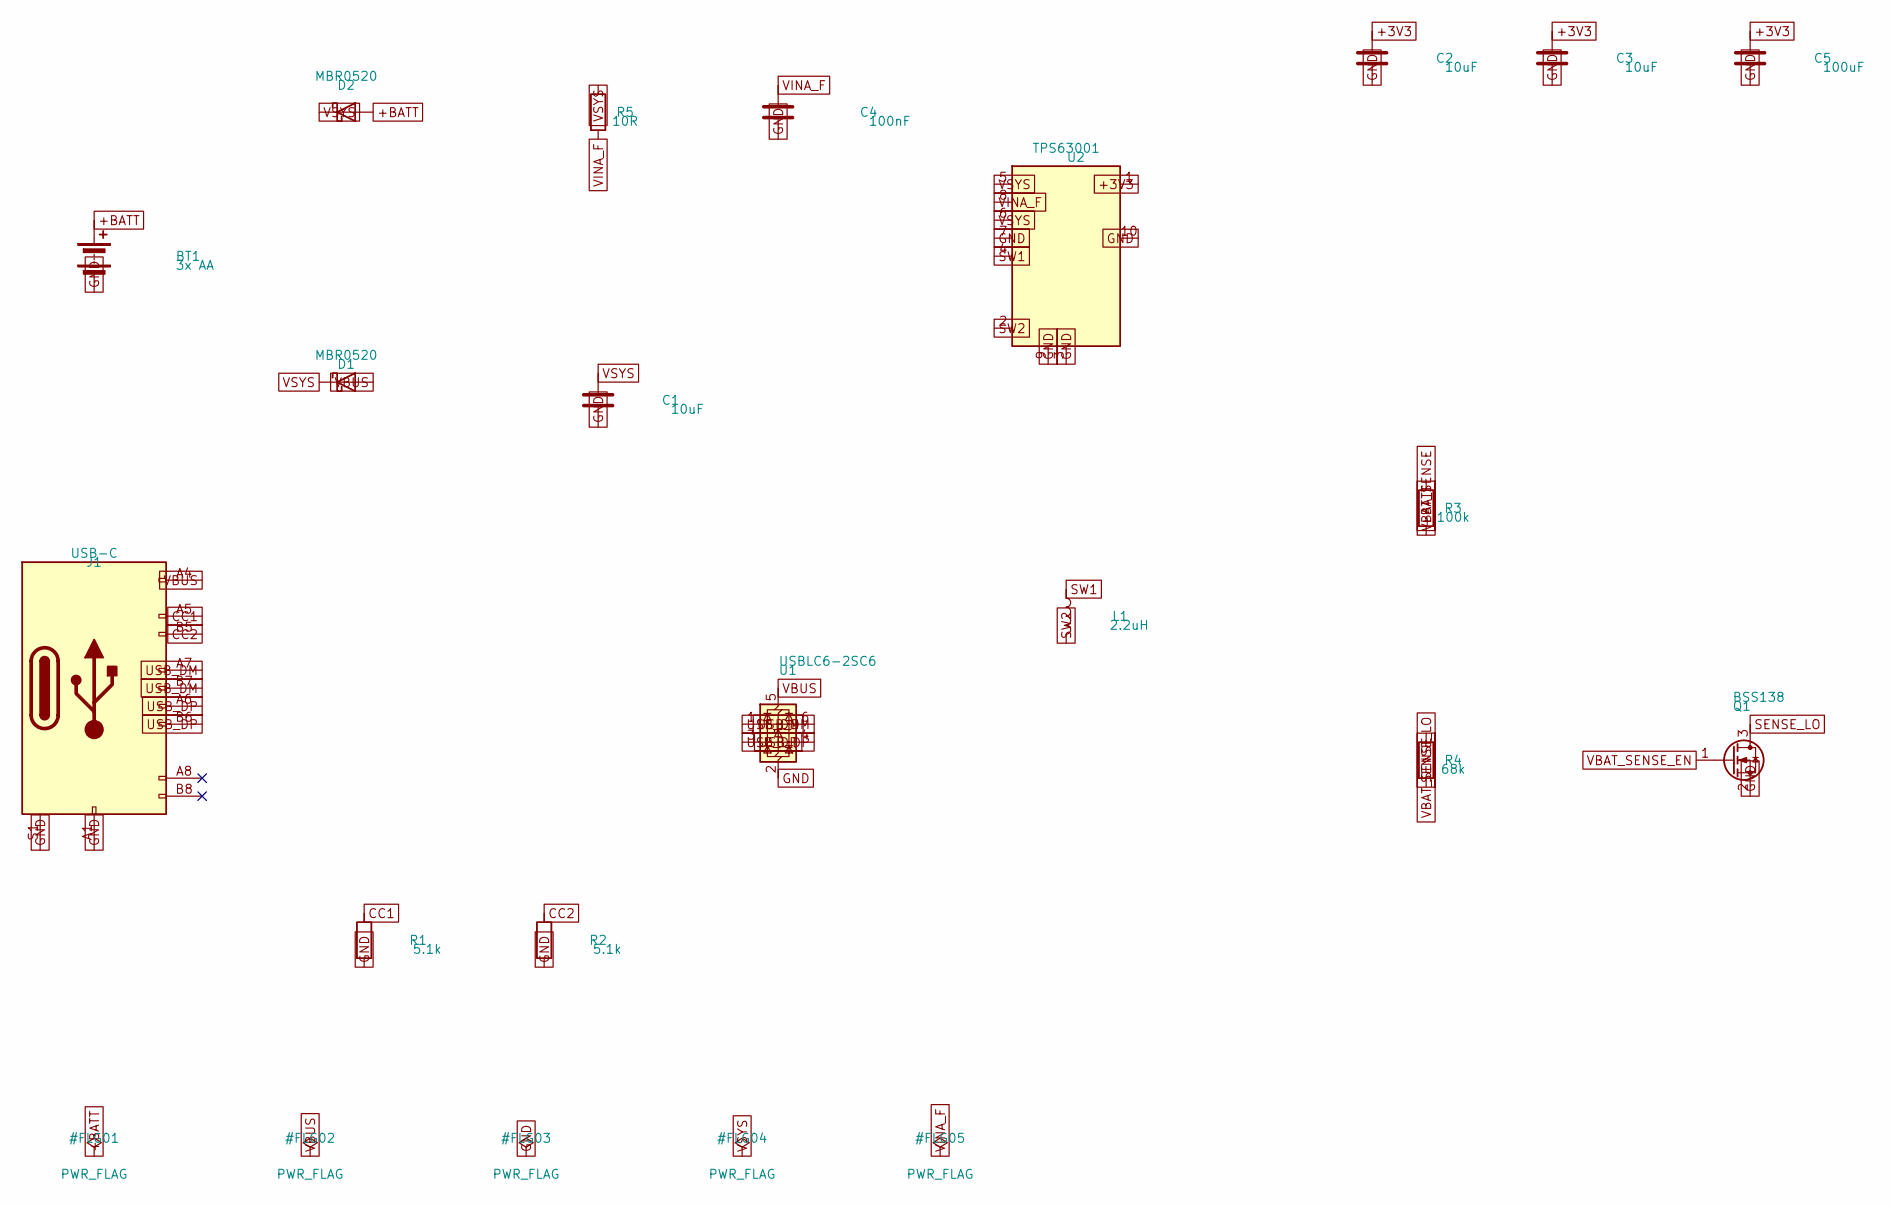
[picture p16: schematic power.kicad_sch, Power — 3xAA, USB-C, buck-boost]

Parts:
BT1: 3x AA; PinHeader_1x02_P2.54mm_Vertical
C1, C2, C3: 10uF; C_0805_2012Metric
C4: 100nF; C_0603_1608Metric
C5: 100uF; C_1210_3225Metric
D1, D2: MBR0520; D_SOD-123
J1: USB-C; USB_C_Receptacle_G-Switch_GT-USB-7010ASV
L1: 2.2uH; L_Bourns-SRN4018
Q1: BSS138; SOT-23
R1, R2: 5.1k; R_0603_1608Metric
R3: 100k; R_0603_1608Metric
R4: 68k; R_0603_1608Metric
R5: 10R; R_0603_1608Metric
U1: USBLC6-2SC6; SOT-23-6
U2: TPS63001; Texas_DRC0010J_ThermalVias

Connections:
+3V3: C2.1, C3.1, C5.1, U2.1 (VOUT); also elsewhere on the board
+BATT: BT1.1 (+), D2.2 (A), R3.1; also elsewhere on the board
CC1: J1.A5 (CC1), R1.1
CC2: J1.B5 (CC2), R2.1
GND: BT1.2 (-), C1.2, C2.2, C3.2, C4.2, C5.2, J1.A1 (GND), J1.A12 (GND), J1.B1 (GND), J1.B12 (GND), J1.S1 (SHIELD), Q1.2 (S), R1.2, R2.2, U1.2 (GND), U2.3 (PGND), U2.7 (PS/SYNC), U2.9 (GND), U2.10 (FB), U2.11 (PGND); also elsewhere on the board
SENSE_LO: Q1.3 (D), R4.2
SW1: L1.1, U2.4 (L1)
SW2: L1.2, U2.2 (L2)
USB_DM: J1.A7 (D-), J1.B7 (D-), U1.1 (I/O1), U1.6 (I/O1); also elsewhere on the board
USB_DP: J1.A6 (D+), J1.B6 (D+), U1.3 (I/O2), U1.4 (I/O2); also elsewhere on the board
VBAT_SENSE: R3.2, R4.1; also elsewhere on the board
VBAT_SENSE_EN: Q1.1 (G); also elsewhere on the board
VBUS: D1.2 (A), J1.A4 (VBUS), J1.A9 (VBUS), J1.B4 (VBUS), J1.B9 (VBUS), U1.5 (VBUS); also elsewhere on the board
VINA_F: C4.1, R5.2, U2.8 (VINA)
VSYS: C1.1, D1.1 (K), D2.1 (K), R5.1, U2.5 (VIN), U2.6 (EN)

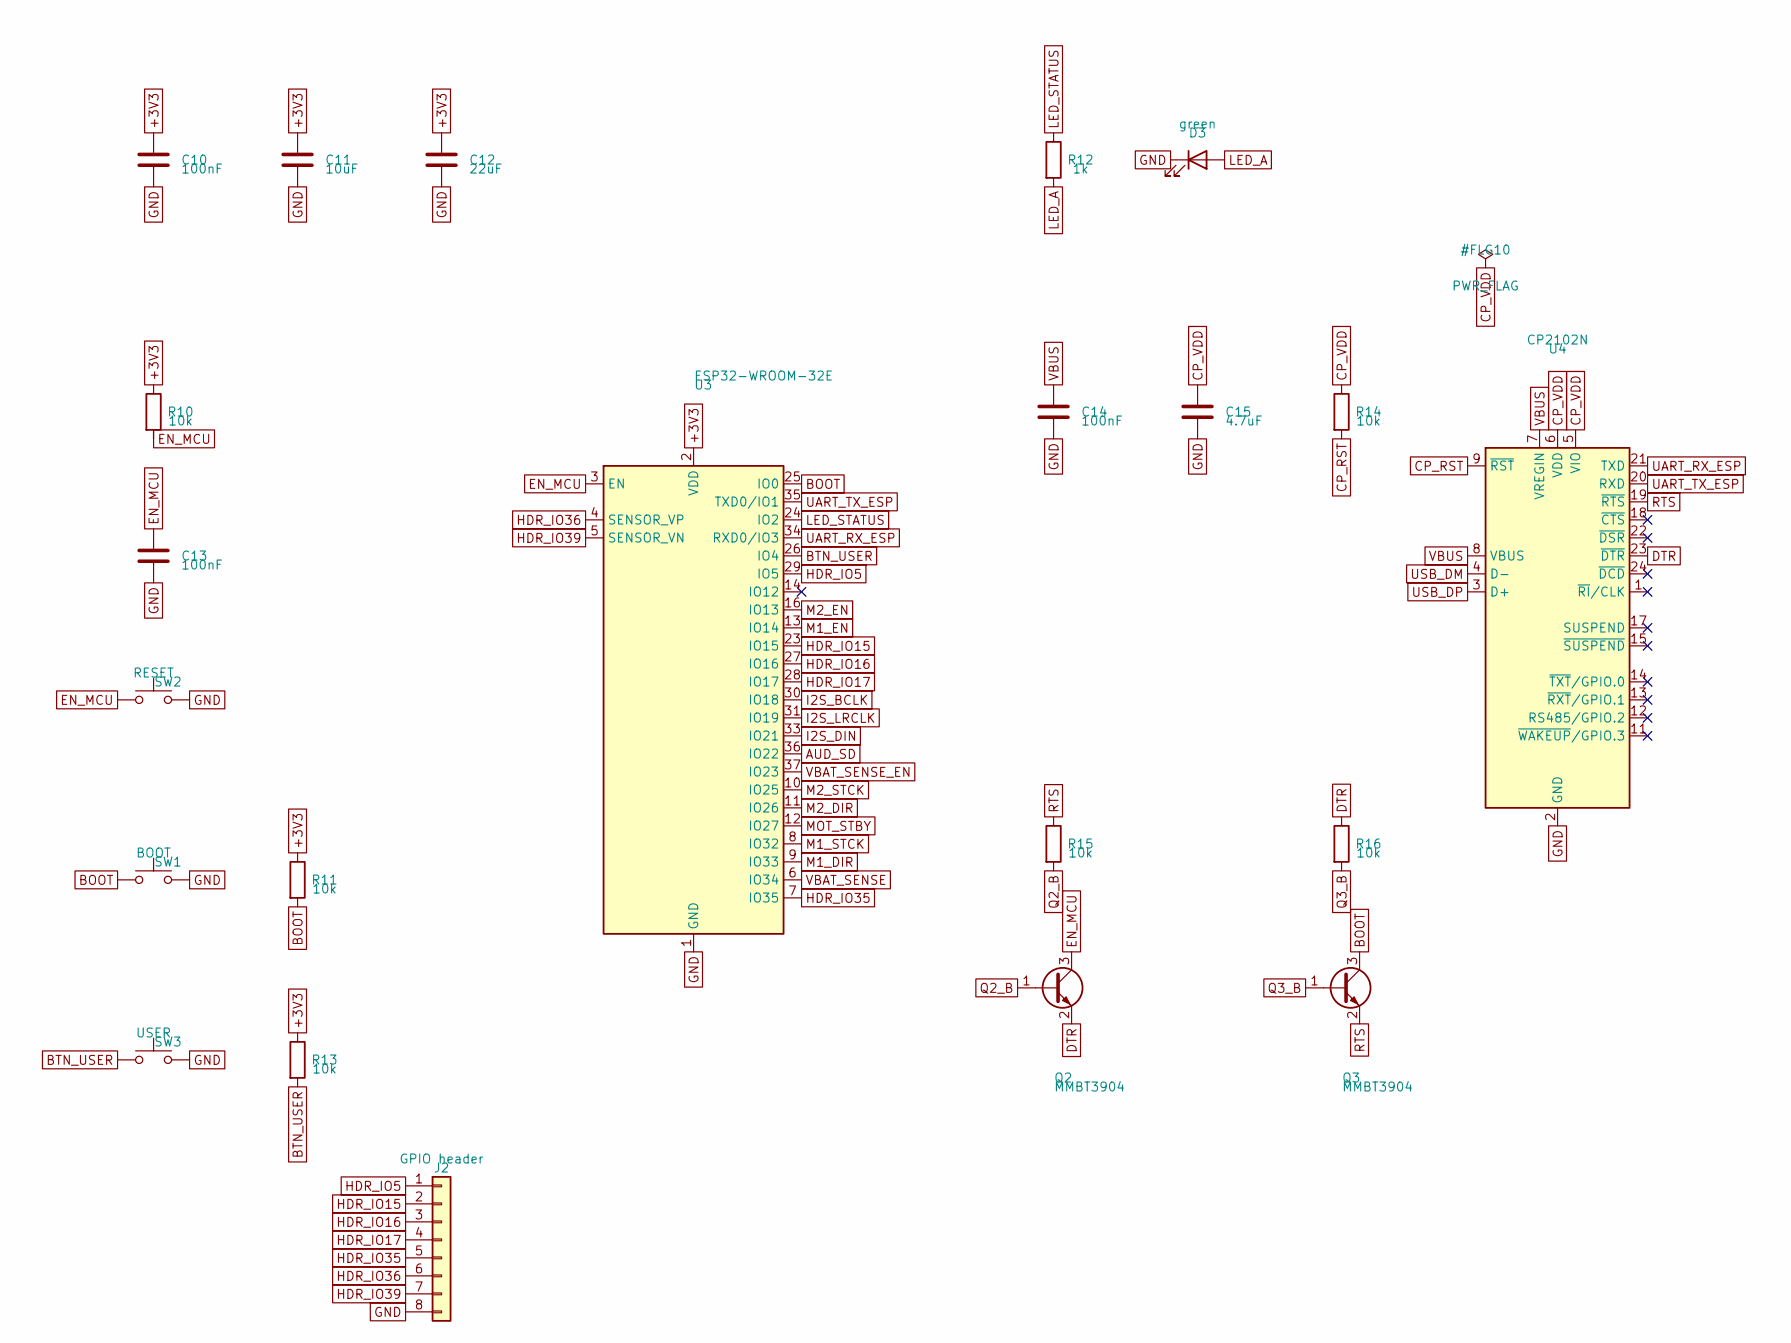
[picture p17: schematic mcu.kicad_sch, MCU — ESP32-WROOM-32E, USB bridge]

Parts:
C10, C13, C14: 100nF; C_0603_1608Metric
C11: 10uF; C_0805_2012Metric
C12: 22uF; C_0805_2012Metric
C15: 4.7uF; C_0805_2012Metric
D3: green; LED_0603_1608Metric
J2: GPIO header; PinHeader_1x08_P2.54mm_Vertical
Q2, Q3: MMBT3904; SOT-23
R10, R11, R13, R14, R15, R16: 10k; R_0603_1608Metric
R12: 1k; R_0603_1608Metric
SW1: BOOT; SW_SPST_SKQG_WithoutStem
SW2: RESET; SW_SPST_SKQG_WithoutStem
SW3: USER; SW_SPST_SKQG_WithoutStem
U3: ESP32-WROOM-32E
U4: CP2102N; QFN-24-1EP_4x4mm_P0.5mm_EP2.15x2.15mm

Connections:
+3V3: C10.1, C11.1, C12.1, R10.1, R11.1, R13.1, U3.2 (VDD); also elsewhere on the board
AUD_SD: U3.36 (IO22); also elsewhere on the board
BOOT: Q3.3 (C), R11.2, SW1.1, U3.25 (IO0)
BTN_USER: R13.2, SW3.1, U3.26 (IO4)
CP_RST: R14.2, U4.9 (~RST)
CP_VDD: C15.1, R14.1, U4.5 (VIO), U4.6 (VDD)
DTR: Q2.2 (E), R16.1, U4.23 (~DTR)
EN_MCU: C13.1, Q2.3 (C), R10.2, SW2.1, U3.3 (EN)
GND: C10.2, C11.2, C12.2, C13.2, C14.2, C15.2, D3.1 (K), J2.8, SW1.2, SW2.2, SW3.2, U3.1 (GND), U3.15 (GND), U3.38 (GND), U3.39 (GND), U4.2 (GND), U4.25 (GND); also elsewhere on the board
HDR_IO5: J2.1, U3.29 (IO5)
HDR_IO15: J2.2, U3.23 (IO15)
HDR_IO16: J2.3, U3.27 (IO16)
HDR_IO17: J2.4, U3.28 (IO17)
HDR_IO35: J2.5, U3.7 (IO35)
HDR_IO36: J2.6, U3.4 (SENSOR_VP)
HDR_IO39: J2.7, U3.5 (SENSOR_VN)
I2S_BCLK: U3.30 (IO18); also elsewhere on the board
I2S_DIN: U3.33 (IO21); also elsewhere on the board
I2S_LRCLK: U3.31 (IO19); also elsewhere on the board
LED_A: D3.2 (A), R12.2
LED_STATUS: R12.1, U3.24 (IO2)
M1_DIR: U3.9 (IO33); also elsewhere on the board
M1_EN: U3.13 (IO14); also elsewhere on the board
M1_STCK: U3.8 (IO32); also elsewhere on the board
M2_DIR: U3.11 (IO26); also elsewhere on the board
M2_EN: U3.16 (IO13); also elsewhere on the board
M2_STCK: U3.10 (IO25); also elsewhere on the board
MOT_STBY: U3.12 (IO27); also elsewhere on the board
Q2_B: Q2.1 (B), R15.2
Q3_B: Q3.1 (B), R16.2
RTS: Q3.2 (E), R15.1, U4.19 (~RTS)
UART_RX_ESP: U3.34 (RXD0/IO3), U4.21 (TXD)
UART_TX_ESP: U3.35 (TXD0/IO1), U4.20 (RXD)
USB_DM: U4.4 (D-); also elsewhere on the board
USB_DP: U4.3 (D+); also elsewhere on the board
VBAT_SENSE: U3.6 (IO34); also elsewhere on the board
VBAT_SENSE_EN: U3.37 (IO23); also elsewhere on the board
VBUS: C14.1, U4.7 (VREGIN), U4.8 (VBUS); also elsewhere on the board

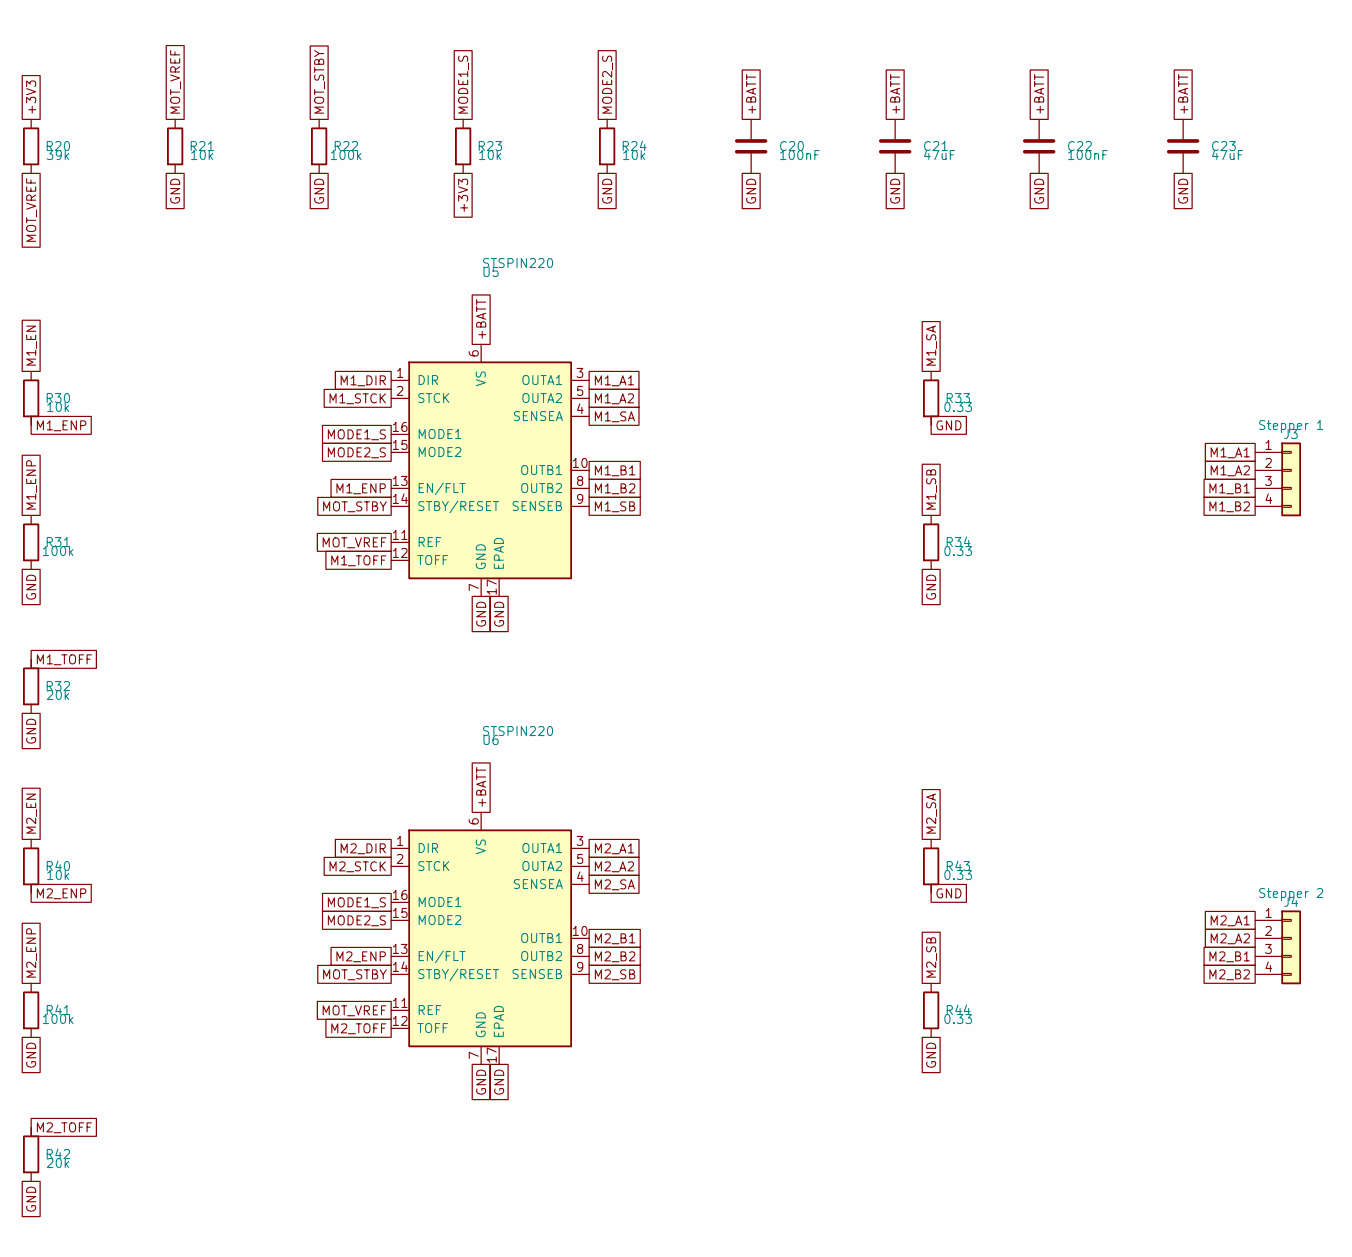
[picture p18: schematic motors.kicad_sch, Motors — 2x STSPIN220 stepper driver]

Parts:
C20, C22: 100nF; C_0603_1608Metric
C21, C23: 47uF; C_1210_3225Metric
J3: Stepper 1; PinHeader_1x04_P2.54mm_Vertical
J4: Stepper 2; PinHeader_1x04_P2.54mm_Vertical
R20: 39k; R_0603_1608Metric
R21, R23, R24, R30, R40: 10k; R_0603_1608Metric
R22, R31, R41: 100k; R_0603_1608Metric
R32, R42: 20k; R_0603_1608Metric
R33, R34, R43, R44: 0.33; R_1206_3216Metric
U5, U6: STSPIN220; QFN-16-1EP_3x3mm_P0.5mm_EP1.45x1.45mm_ThermalVias

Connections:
+3V3: R20.1, R23.2; also elsewhere on the board
+BATT: C20.1, C21.1, C22.1, C23.1, U5.6 (VS), U6.6 (VS); also elsewhere on the board
GND: C20.2, C21.2, C22.2, C23.2, R21.2, R22.2, R24.2, R31.2, R32.2, R33.2, R34.2, R41.2, R42.2, R43.2, R44.2, U5.7 (GND), U5.17 (EPAD), U6.7 (GND), U6.17 (EPAD); also elsewhere on the board
M1_A1: J3.1, U5.3 (OUTA1)
M1_A2: J3.2, U5.5 (OUTA2)
M1_B1: J3.3, U5.10 (OUTB1)
M1_B2: J3.4, U5.8 (OUTB2)
M1_DIR: U5.1 (DIR); also elsewhere on the board
M1_EN: R30.1; also elsewhere on the board
M1_ENP: R30.2, R31.1, U5.13 (EN/FLT)
M1_SA: R33.1, U5.4 (SENSEA)
M1_SB: R34.1, U5.9 (SENSEB)
M1_STCK: U5.2 (STCK); also elsewhere on the board
M1_TOFF: R32.1, U5.12 (TOFF)
M2_A1: J4.1, U6.3 (OUTA1)
M2_A2: J4.2, U6.5 (OUTA2)
M2_B1: J4.3, U6.10 (OUTB1)
M2_B2: J4.4, U6.8 (OUTB2)
M2_DIR: U6.1 (DIR); also elsewhere on the board
M2_EN: R40.1; also elsewhere on the board
M2_ENP: R40.2, R41.1, U6.13 (EN/FLT)
M2_SA: R43.1, U6.4 (SENSEA)
M2_SB: R44.1, U6.9 (SENSEB)
M2_STCK: U6.2 (STCK); also elsewhere on the board
M2_TOFF: R42.1, U6.12 (TOFF)
MODE1_S: R23.1, U5.16 (MODE1), U6.16 (MODE1)
MODE2_S: R24.1, U5.15 (MODE2), U6.15 (MODE2)
MOT_STBY: R22.1, U5.14 (STBY/RESET), U6.14 (STBY/RESET); also elsewhere on the board
MOT_VREF: R20.2, R21.1, U5.11 (REF), U6.11 (REF)

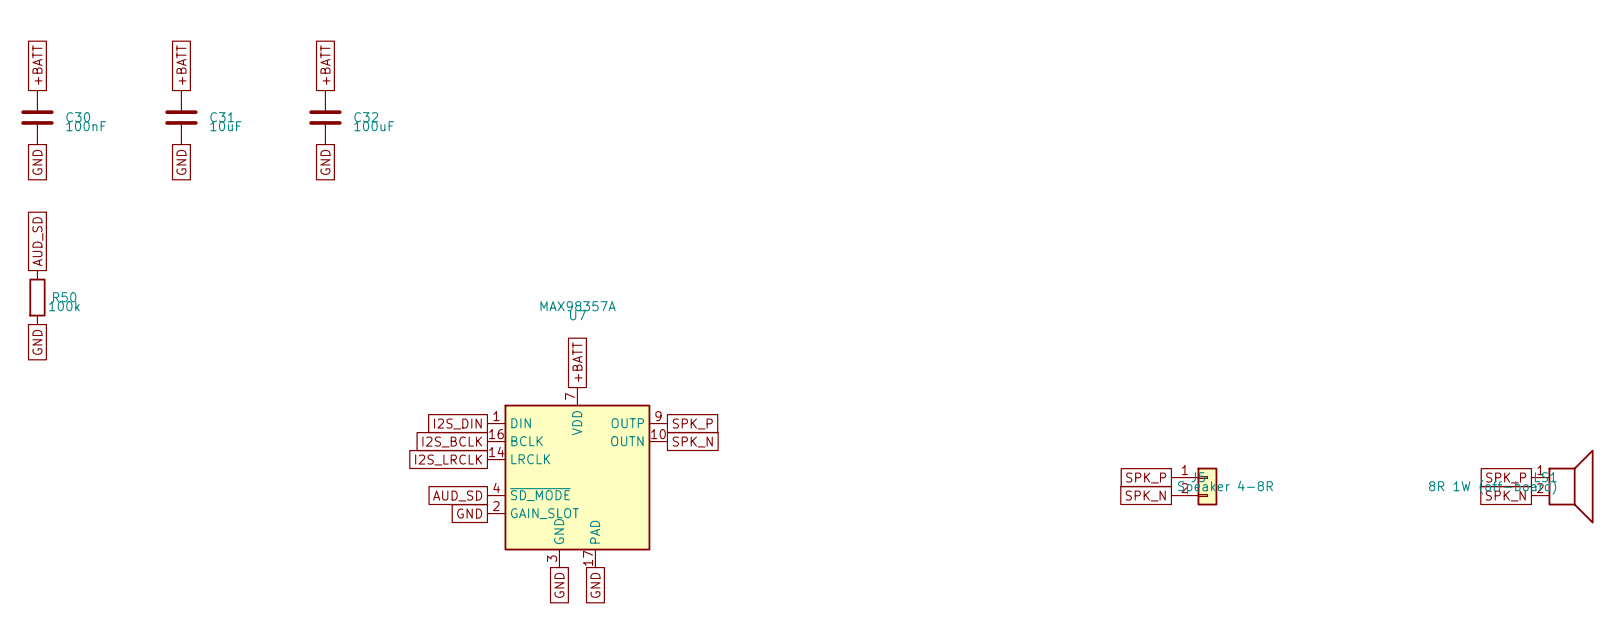
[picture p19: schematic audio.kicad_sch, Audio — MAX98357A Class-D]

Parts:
C30: 100nF; C_0603_1608Metric
C31: 10uF; C_0805_2012Metric
C32: 100uF; C_1210_3225Metric
J5: Speaker 4-8R; PinHeader_1x02_P2.54mm_Vertical
LS1: 8R 1W (off-board)
R50: 100k; R_0603_1608Metric
U7: MAX98357A; QFN-16-1EP_3x3mm_P0.5mm_EP1.45x1.45mm_ThermalVias

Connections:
+BATT: C30.1, C31.1, C32.1, U7.7 (VDD), U7.8 (VDD); also elsewhere on the board
AUD_SD: R50.1, U7.4 (~SD_MODE); also elsewhere on the board
GND: C30.2, C31.2, C32.2, R50.2, U7.2 (GAIN_SLOT), U7.3 (GND), U7.11 (GND), U7.15 (GND), U7.17 (PAD); also elsewhere on the board
I2S_BCLK: U7.16 (BCLK); also elsewhere on the board
I2S_DIN: U7.1 (DIN); also elsewhere on the board
I2S_LRCLK: U7.14 (LRCLK); also elsewhere on the board
SPK_N: J5.2, LS1.2, U7.10 (OUTN)
SPK_P: J5.1, LS1.1, U7.9 (OUTP)

Board: 4 copper layers, 69 parts (0 on the bottom side), 67 nets, no tracks yet.

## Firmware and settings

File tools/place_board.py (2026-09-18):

#!/usr/bin/env python3
"""Deliberate placement for isc-motorbeep, with a self-check.

Board is 70 x 50 mm, origin top-left, y increasing downward.

Two footprint facts drive the coordinates, both measured rather than assumed:

  * Pin headers (J2, J3, J4, J5, BT1) have their ORIGIN AT PIN 1, not at their
    centre, and extend +Y from there -- J2 (1x08) reaches +19.6 mm. Placing
    them by centre puts them through the board edge.
  * U3's courtyard is x +-24.3, y -28..+13.6 because it includes the antenna
    keepout. The module BODY is only x +-9, y -6.6..+13.6. Overlap checking
    against the courtyard gives false positives for every part beside the
    module, so the check below uses the body for U3 and the keepout separately.

Floorplan: U3 top-left with its antenna overhanging the top edge; USB chain
(J1 -> U1 -> U4) top-right; buck-boost bottom-right with L1 hard against U2 so
the SW1/SW2 switching loop stays small; the two motor channels down the left
edge, each next to its own connector; audio bottom-centre.
"""
import pcbnew, sys, itertools

BOARD = "/home/pmudry/git/cad-demo/hardware/isc-motorbeep/isc-motorbeep.kicad_pcb"
W, H, MARGIN = 70.0, 50.0, 0.5

PLACE = {
    # MCU, top-left. U3 first; its antenna hangs off the top edge.
    "U3": (22, 9), "R10": (5, 5), "C13": (5, 9), "SW2": (5, 15), "SW1": (5, 22),
    "C10": (14, 25), "C11": (18, 25), "C12": (22, 25),
    "D3": (36, 5), "R12": (40, 5), "SW3": (38, 12), "R13": (36, 18), "R11": (41, 18),
    "J2": (46, 5),
    # USB-C -> ESD -> bridge, top-right, in that physical order.
    "J1": (61, 6), "R1": (52, 4), "R2": (52, 8),
    "U1": (61, 14), "U4": (60, 22),
    "C14": (52, 13), "C15": (52, 17), "R14": (52, 21),
    "R15": (67, 14), "Q2": (67, 19), "Q3": (67, 25), "R16": (56, 27),
    # Buck-boost, bottom-right. L1 sits 1.7 mm below U2: this gap IS the
    # switching loop, and it is the one dimension worth protecting.
    # L1 sits directly LEFT of U2, rotated 90 so its two pads line up with the
    # SW1/SW2 pins. Those pins are pads 2 and 4 of a 0.5 mm-pitch column, so
    # this is the only geometry that gets both switching nodes out as short
    # straight traces instead of routing them around the package.
    "U2": (54, 34), "L1": (48.5, 34, 90),
    "C1": (50.5, 38), "C4": (58, 30), "R5": (58, 27),
    "C2": (50.5, 30), "C3": (54, 29.5), "C5": (61, 34),
    "D1": (48, 44), "D2": (53, 46), "Q1": (60, 45),
    "R3": (64, 33), "R4": (64, 37), "BT1": (67, 43),
    # Motor 1 then motor 2, down the left edge beside their connectors.
    "J3": (3, 27.5), "U5": (13, 31),
    "R30": (9, 28), "R31": (9, 34), "R32": (24, 31),
    "R33": (18, 29), "R34": (18, 33), "C20": (13, 27), "C21": (24, 27),
    "J4": (3, 39), "U6": (13, 43),
    "R40": (9, 40), "R41": (9, 46), "R42": (24, 43),
    "R43": (18, 41), "R44": (18, 45), "C22": (13, 39), "C23": (24, 39),
    "R20": (28.5, 29), "R21": (28.5, 33), "R22": (28.5, 37),
    "R23": (28.5, 41), "R24": (28.5, 45),
    # Audio, bottom-centre, speaker connector on the bottom edge.
    "U7": (36, 38), "R50": (41, 38), "J5": (36, 45),
    "C30": (32, 33), "C31": (36, 33), "C32": (40, 33),
}

# Anchors keep their coordinates exactly: connectors must stay on their edge,
# and U2/L1 must stay adjacent or the switching loop grows. Everything else is
# a passive that may be nudged to the nearest free spot.
ANCHORS = {"U3","U2","L1","U1","U4","U5","U6","U7",
           "J1","J2","J3","J4","J5","BT1","SW1","SW2","SW3","D1","D2"}

# U3: real body, and the copper/footprint keepout, relative to its origin.
U3_BODY    = (-9.0, 9.0, -6.6, 13.6)
U3_KEEPOUT = (-24.3, 24.3, -28.0, -6.6)

def extent(f):
    """Origin-relative (x0,x1,y0,y1) of a footprint's courtyard, in mm."""
    o = f.GetPosition(); cy = f.GetCourtyard(pcbnew.F_CrtYd)
    bb = cy.BBox() if cy.OutlineCount() else f.GetBoundingBox()
    return ((bb.GetLeft()-o.x)/1e6, (bb.GetRight()-o.x)/1e6,
            (bb.GetTop()-o.y)/1e6, (bb.GetBottom()-o.y)/1e6)

def box(f):
    o = f.GetPosition(); ox, oy = o.x/1e6, o.y/1e6
    if f.GetReference() == "U3":
        x0, x1, y0, y1 = U3_BODY
    else:
        x0, x1, y0, y1 = extent(f)
    return (ox+x0, ox+x1, oy+y0, oy+y1)

def overlap(a, b, tol=0.0):
    return (a[0] < b[1]-tol and b[0] < a[1]-tol and
            a[2] < b[3]-tol and b[2] < a[3]-tol)

def main():
    b = pcbnew.LoadBoard(BOARD)
    for ref, spec in PLACE.items():
        x, y, rot = (spec + (0,))[:3] if len(spec) == 2 else spec
        f = b.FindFootprintByReference(ref)
        if f is None:
            print(f"  !! {ref} not on board"); continue
        f.SetPosition(pcbnew.VECTOR2I(pcbnew.FromMM(x), pcbnew.FromMM(y)))
        f.SetOrientationDegrees(rot)

    fps = list(b.GetFootprints())

    # Resolve overlaps: walk the non-anchor parts and, for any that collides,
    # search outward on a 0.5 mm grid for the nearest position that is free and
    # on-board. Anchors never move.
    u3 = b.FindFootprintByReference("U3"); uo = u3.GetPosition()
    keep = (uo.x/1e6+U3_KEEPOUT[0], uo.x/1e6+U3_KEEPOUT[1],
            uo.y/1e6+U3_KEEPOUT[2], uo.y/1e6+U3_KEEPOUT[3])

    def fits(ref, bx, others):
        if bx[0] < MARGIN or bx[1] > W-MARGIN or bx[2] < MARGIN or bx[3] > H-MARGIN:
            return False
        if overlap(bx, keep, tol=0.05):
            return False
        return not any(overlap(bx, ob, tol=0.05) for r, ob in others.items() if r != ref)

    placed_boxes = {f.GetReference(): box(f) for f in fps}
    moved = []
    for f in fps:
        ref = f.GetReference()
        if ref in ANCHORS:
            continue
        if fits(ref, placed_boxes[ref], placed_boxes):
            continue
        o = f.GetPosition(); ox, oy = o.x/1e6, o.y/1e6
        ex = extent(f)
        found = None
        for radius in [r*0.5 for r in range(1, 41)]:
            for dx, dy in [(radius,0),(-radius,0),(0,radius),(0,-radius),
                           (radius,radius),(-radius,radius),(radius,-radius),(-radius,-radius)]:
                nx, ny = ox+dx, oy+dy
                cand = (nx+ex[0], nx+ex[1], ny+ex[2], ny+ex[3])
                if fits(ref, cand, placed_boxes):
                    found = (nx, ny, cand); break
            if found: break
        if found:
            nx, ny, cand = found
            f.SetPosition(pcbnew.VECTOR2I(pcbnew.FromMM(nx), pcbnew.FromMM(ny)))
            placed_boxes[ref] = cand
            moved.append(f"{ref} -> ({nx:.1f}, {ny:.1f})")
    if moved:
        print(f"nudged {len(moved)}: " + ", ".join(moved))

    boxes = {f.GetReference(): box(f) for f in fps}
    problems = []
    for ref, bx in boxes.items():
        if bx[0] < MARGIN or bx[1] > W-MARGIN or bx[2] < MARGIN or bx[3] > H-MARGIN:
            problems.append(f"off-board/at-edge: {ref} "
                            f"x {bx[0]:.1f}..{bx[1]:.1f} y {bx[2]:.1f}..{bx[3]:.1f}")
    for (r1, b1), (r2, b2) in itertools.combinations(boxes.items(), 2):
        if overlap(b1, b2, tol=0.05):
            problems.append(f"overlap: {r1} / {r2}")
    # nothing may sit inside U3's antenna keepout
    u3 = b.FindFootprintByReference("U3"); o = u3.GetPosition()
    ko = (o.x/1e6+U3_KEEPOUT[0], o.x/1e6+U3_KEEPOUT[1],
          o.y/1e6+U3_KEEPOUT[2], o.y/1e6+U3_KEEPOUT[3])
    for ref, bx in boxes.items():
        if ref != "U3" and overlap(bx, ko, tol=0.05):
            problems.append(f"inside antenna keepout: {ref}")

    b.Save(BOARD)
    print(f"placed {len(PLACE)}/{len(fps)} footprints on a {W:.0f}x{H:.0f} mm board")
    if problems:
        print(f"{len(problems)} problem(s):")
        for p in problems: print("  " + p)
        return 1
    print("no overlaps, nothing off-board, antenna keepout clear")
    return 0

if __name__ == "__main__":
    sys.exit(main())

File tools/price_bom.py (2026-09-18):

#!/usr/bin/env python3
"""Price the BOM against the local JLCPCB catalog.

Reads doc/isc-motorbeep-bom.csv, asks the KiCAD-MCP-Server's offline JLCPCB
database for each line, and writes a Markdown table with real LCSC part
numbers, unit prices and stock. Every figure is traceable to an LCSC code —
nothing is estimated. Re-run after `download_jlcpcb_database` to refresh.

    python tools/price_bom.py            # prints the Markdown table
"""
import csv, json, re, subprocess, sys, pathlib

ROOT = pathlib.Path(__file__).resolve().parent.parent
SRV  = ROOT / "tools" / "kicad-mcp-server"
BOM  = ROOT / "doc" / "isc-motorbeep-bom.csv"

# BOM value -> (JLCPCB query, package filter). Keyed on the Value column so the
# mapping stays readable; passives are matched on value + package.
Q = {
    "ESP32-WROOM-32E": ("ESP32-WROOM-32E", None),
    "TPS63001":        ("TPS63001", None),
    "STSPIN220":       ("STSPIN220", None),
    "MAX98357A":       ("MAX98357A", None),
    "CP2102N":         ("CP2102N", None),
    "USBLC6-2SC6":     ("USBLC6-2SC6", None),
    "BSS138":          ("BSS138", "SOT-23"),
    "MMBT3904":        ("MMBT3904", "SOT-23"),
    "MBR0520":         ("MBR0520 schottky", "SOD-123"),
    "2.2uH":           ("2.2uH power inductor", None),
    "green":           ("green LED 0603", "0603"),
    "USB-C":           ("Type-C 16P connector", None),
    "0.33":            ("330mΩ 1206", None),
}
PASSIVE_PKG = {"Resistor_SMD:R_0603_1608Metric": ("0603", "resistor"),
               "Resistor_SMD:R_1206_3216Metric": ("1206", "resistor"),
               "Capacitor_SMD:C_0603_1608Metric": ("0603", "capacitor"),
               "Capacitor_SMD:C_0805_2012Metric": ("0805", "capacitor"),
               "Capacitor_SMD:C_1210_3225Metric": ("1210", "capacitor")}
SKIP = {"8R 1W (off-board)"}   # not a board part
MECH = {"3x AA", "GPIO header", "Stepper 1", "Stepper 2", "Speaker 4-8R",
        "BOOT", "RESET", "USER"}   # generic mechanical, priced as a class

def rows():
    with open(BOM) as f:
        for r in csv.DictReader(f):
            yield r

def query_for(r):
    v, fp = r["Value"], r["Footprint"]
    if v in SKIP: return None
    if v in Q: return Q[v][0], Q[v][1]
    if fp in PASSIVE_PKG:
        pkg, kind = PASSIVE_PKG[fp]
        return f"{v} {kind} {pkg}", pkg
    if "PinHeader_1x" in fp:
        # JLCPCB sells 2.54 mm headers as a 1x40 strip you cut to length; all
        # five headers here total 20 pins, so it is one strip, counted once.
        return "1x40P 2.54mm pin header", None
    if "SW_SPST" in fp: return "tactile switch SMD", None
    return v, None

def main():
    calls, meta = [], []
    for r in rows():
        q = query_for(r)
        if q is None:
            meta.append((r, None)); continue
        args = {"query": q[0], "limit": 8}
        if q[1]: args["package"] = q[1]
        calls.append({"tool": "search_jlcpcb_parts", "args": args})
        meta.append((r, len(calls) - 1))

    tmp = ROOT / ".price_batch.json"
    tmp.write_text(json.dumps(calls))
    out = subprocess.run(["node", "kmcp.mjs", "batch", str(tmp)],
                         cwd=SRV, capture_output=True, text=True, timeout=1800).stdout
    tmp.unlink(missing_ok=True)
    blocks = re.split(r"^--- \[\d+\] .*?---$", out, flags=re.M)[1:]

    PAT = re.compile(r"(C\d+): (.+?) - .*?\$([\d.]+)/ea \((\d+) in stock\)")
    lines, total, unpriced, seen_pooled = [], 0.0, [], set()
    for r, idx in meta:
        qty = int(r["QUANTITY"])
        ref, val, fp = r["Reference"], r["Value"], r["Footprint"]
        pkg = fp.split(":")[-1] if fp else "—"
        hit = None
        if idx is not None and idx < len(blocks):
            m = PAT.findall(blocks[idx])
            if m:
                # Cheapest *sourceable* part: a 13-in-stock line item is not a
                # real price. Prefer anything with healthy stock, then price.
                stocked = [x for x in m if int(x[3]) >= 500] or m
                hit = min(stocked, key=lambda x: float(x[2]))
        if hit:
            lcsc, _desc, price, stock = hit
            pooled = "PinHeader_1x" in fp
            if pooled and lcsc in seen_pooled:
                lines.append(f"| `{ref}` | {val} | {pkg} | [{lcsc}](https://jlcpcb.com/partdetail/{lcsc[1:]}) | {qty} | — | *(same strip)* | {int(stock):,} |")
                continue
            if pooled: seen_pooled.add(lcsc)
            line = (1 if pooled else qty) * float(price)
            total += line
            lines.append(f"| `{ref}` | {val} | {pkg} | [{lcsc}](https://jlcpcb.com/partdetail/{lcsc[1:]}) | {qty} | {float(price):.4f} | **{line:.2f}** | {int(stock):,} |")
        else:
            unpriced.append(f"{ref} ({val})")
            lines.append(f"| `{ref}` | {val} | {pkg} | — | {qty} | — | — | — |")

    md = ["# Bill of materials — ISC MotorBeep", "",
          "Generated by `tools/price_bom.py` from the KiCAD-MCP-Server's offline JLCPCB",
          "catalog. Prices are 1-off LCSC breaks and **move constantly** — re-run after a",
          "`download_jlcpcb_database` to refresh. Each row links to its part page.", "",
          "| Ref | Value | Package | LCSC | Qty | Unit $ | Line $ | Stock |",
          "|---|---|---|---|---:|---:|---:|---:|", *lines, "",
          f"**Total: ${total:.2f} in parts for one board.**", "",
          "## Notes", "",
          "- `LS1` is the off-board speaker, deliberately unpriced — `J5` is the connector on the board.",
          "- All five 2.54 mm headers are cut from one 1x40 strip (20 pins of 40), so the strip is counted once.",
          "- Almost everything here is a JLCPCB *Extended* part, which carries a $3 setup fee each if you",
          "  use their assembly service; for a one-off, hand assembly is cheaper than the setup fees.", "",
          "## If the STSPIN220 is out of stock", "",
          "It is the scarcest part in the design. The closest replacement is the **DRV8834**",
          "(`C400392`, VQFN-24, or `C456273`, HTSSOP-24, ~$2.40). Its 2.5–10.8 V range still covers a",
          "3x AA pack for its useful life, but it is not a drop-in: different footprint, and KiCad 9",
          "ships no DRV8834 symbol, so the motors sheet would need a custom symbol and footprint.",
          ""]
    out_md = "\n".join(md)
    (ROOT / "doc" / "BOM.md").write_text(out_md)
    print(out_md)
    if unpriced:
        print(f"\nNot matched automatically: {', '.join(unpriced)}", file=sys.stderr)

if __name__ == "__main__":
    main()

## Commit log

2026-09-18 ISC MotorBeep: ESP32 dual-stepper + audio board schematic
    Complete KiCad 9 hierarchical schematic for an ESP32 board driving two
    bipolar steppers and a small speaker from 3x AA cells, as an improved
    derivative of the ESP32 DevKit DOIT v1.
    Design:
    - 3x AA (2.8-4.8 V) sits inside the STSPIN220 and MAX98357A supply ranges,
    so motors and audio run straight off the battery; only the 3.3 V logic
    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
    [audio.kicad_sch, isc-motorbeep-bom.csv, isc-motorbeep.kicad_pcb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]
2026-09-18 Cite ESP32 datasheet supply spec and date the price snapshot
    ESP32-WROOM-32E Table 14 (Recommended Operating Conditions) confirms
    VDD33 = 3.0/3.3/3.6 V and requires the external supply to deliver 0.5 A
    minimum. Recorded as a specified requirement rather than an estimate in
    the DESIGN.md open item about the TPS63001 low-Vin curve.
    JLCPCB prices and stock are a 14 Sep 2026 snapshot; the STSPIN220 stock
    warning and the BOM total now say so, since both will drift.
2026-09-18 Trim README to the project page; retract a wrong USB-C claim
    README goes from 280 to 108 lines. Everything about the MCP generation
    pipeline (how it was built, the scripts, the KiCad 10 -> 9 format patch,
    the traps) moves to doc/TOOLING.md, and the 36-row priced BOM table moves
    to doc/BOM.md, which tools/price_bom.py now writes. What is left is what
    a reader landing on the repo cold needs: what the board is, the sheets,
    the architecture in one paragraph, the cost, and the two open questions.
    Corrections, all from a bug in tools/pins.py:
    - The claim that no stock footprint matches the USB-C symbol was WRONG.
    pins.py used a bounded lookahead over (pin ...) blocks and silently
    dropped pin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
    [pins.py, price_bom.py]
2026-09-18 Add placed 4-layer PCB and 3D renders
    70 x 50 mm, 4 copper layers, all 69 footprints placed. Not routed: no
    tracks, no zones.
    Placement is generated by tools/place_board.py, which verifies its own
    output -- no courtyard overlaps, nothing off-board, nothing inside the
    ESP32 antenna keepout -- and nudges non-anchor passives to the nearest
    free spot when a hand-chosen coordinate collides.
    Two footprint facts the script encodes, both measured rather than assumed:
    pin headers have their origin at pin 1 and extend +Y (J2 reaches 19.6 mm,
    so placing it by centre pushes it through the board edge), and U3's
    courtyard is inflated to x +-24.3 mm by the antenna keepout, which makes
    courtyard-based ove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
    [isc-motorbeep.kicad_pcb]
2026-09-18 Render the board in 3D with component bodies
    kicad-packages3d is a root install, so the STEP models were fetched into
    ~/.local/share instead and reached through KICAD9_3DMODEL_DIR, which the
    footprints already reference. Method recorded in doc/TOOLING.md.
    The GitLab archive ships only .step, no .wrl -- fine, since KiCad 9
    footprints point at .step directly.
    Four footprints have no model in the library (G-Switch USB-C, QFN-16 3x3
    EP1.45, QFN-24 4x4 EP2.15, Texas DRC0010J). tools/fix_3d_models.py
    repoints them at equivalent bodies for rendering only: same package and
    pin count, different exposed-pad size, which sits under the part. Pads,
    courtyards and nets are untouched.
    Incidental datapoi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
    [isc-motorbeep.kicad_pcb]
2026-09-18 State the original brief and a summary of the work in the README
    A reader landing on the repo could see what the board is but not what was
    asked for, nor how far it got. Two short sections up front: the brief as
    given (DOIT v1 as reference, two steppers and a speaker, AA cells, KiCad
    via the MCP server), and seven lines on what was actually built --
    including the two things a reader should not have to dig for: root ERC is
    at 0 errors, and the PCB is placed but not routed.
